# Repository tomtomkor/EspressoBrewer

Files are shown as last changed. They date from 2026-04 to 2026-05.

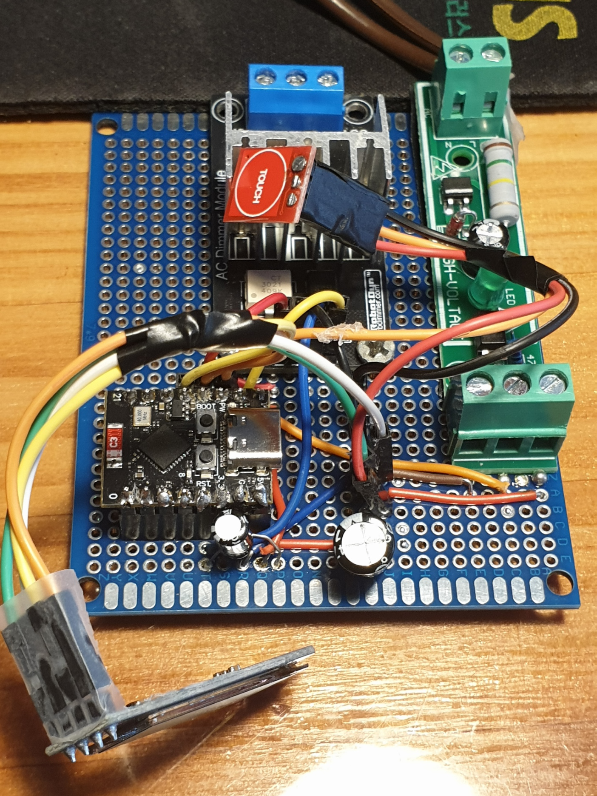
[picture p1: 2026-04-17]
Wiring.jpg

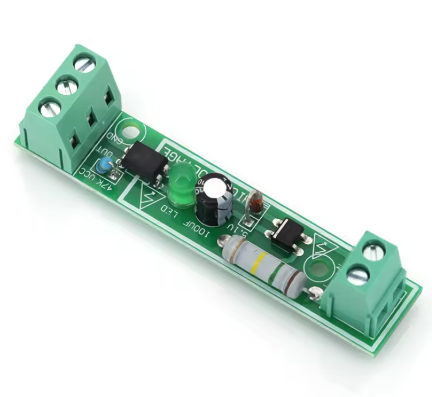
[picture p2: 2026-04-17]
Photos/optocoupler.png

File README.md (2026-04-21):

# ☕ Brew Automation (ESP32-C3)

This project automates the espresso brewing process into three distinct phases: **Pre-infusion**, **Blooming**, and **Extraction**. By adding a dimmer and an ESP32-C3 to a classic machine like the Gaggia Classic, you can achieve custom pressure profiling based on your favorite recipes.

---

## 🛠 Hardware Requirements

* **Controller:** ESP32-C3 SuperMini (chosen for its compact form factor)
* **Dimmer:** Robotdyn AC Dimmer module (4A or higher model; controls pump power)
* **Sensor:** AC Optocoupler isolation module or 110V/220V AC Voltage Detection Module Output Level 3-8V (detects the status of the extraction button)
* **Input:** TTP223 Touch sensor (Mode toggle: Manual / Automatic Brew)
* **Display:** 0.91" OLED (I2C)
* **Power Stability:** 100µF or higher Capacitor for dimmer (recommended for stabilizing power to the Dimmer/Pump logic.  Place the capacitor like a bridge between the 5V and GND pins on ESP32C3. Make sure the minus(-) side goes to GND.)
* **Build:** Perfboard (7x9 cm recommended to withstand pump vibration)
* **Case:** 3D printed enclosure (`EspressoBrewerCase.stl` included)

> **Note:** 5V output of ESP32C3 to Dimmer. 3.3V to other modules.

---

## 📱 Software

* **Arduino Code (`EspressoBrewer.ino`):** Should be compiled and uploaded to ESP32-C3 via Arduino IDE.
* **Mobile App (`BrewMate.apk`):** Built using [MIT App Inventor](https://appinventor.mit.edu).
  * The associated source file (`BrewMate.aia`) is uploaded; you can modify and rebuild it if needed.

---

## 🔄 Workflow

1. **Manual Mode (Default):** On power-up, the machine starts in Manual mode. The pump operates at full capacity, allowing you to purge air or flush the group head.
2. **Mode Toggle:** Tap the touch sensor to switch between **Manual** and **Brew** modes.
3. **Warm-up:** In Brew mode, the system waits for a warmup period (Default: 5 min). 
   * *Note: Based on my Gaggia Classic with PID (XMT 7100), it takes about 5 minutes for the 105°C boiler temp to stabilize. You can adjust the `warmupLimit` variable in the Arduino file.*
4. **Pre-infusion:** Turn the extraction switch ON. The pump runs at a user-specified power level for a set duration(0~20 seconds).
5. **Blooming:** The pump stops completely for a "pause" or blooming phase(0~60s).
6. **Ramping Up:** Pump power gradually increases from 0% to the user-specified max level over 0~15 seconds .
7. **Extraction:** Maintains the specified max pump power until the extraction button is turned OFF manually.
8. **Back-to-Back:** After a shot, the machine reheats and returns to "Ready" status in 2 minutes. (This duration is also adjustable in the CoffeeBrewer.ino file.)
9. **Back Flushing:** Switch to Manual mode via the touch sensor to perform flushing as needed.

---

## ⚙️ Setting Parameters (Mobile App)

You can adjust parameters and manage profiles using the **BrewMate** app:

* **PreTime:** Pre-infusion duration

* **PrePower:** Pump power during pre-infusion

* **Pause:** Blooming duration

* **RampUp:** Duration to reach max power

* **MxPower:** Maximum pump power (e.g., set below 100% for "Turbo Shots")
  
  Multiple brewing profiles can be stored on the mobile app. Users can select a profile by name to sync with the ESP32-C3 for immediate application.

**Connection Details:**

* The app requests the local IP address assigned to the ESP32-C3 (e.g., `192.168.0.110`) on first launch.
* Configure your **SSID**, **Password**, and **Static IP** within the `EspressoBrewer.ino` file.
* The app is designed to be intuitive and can be mastered in minutes without a manual.

---

## 🔌 Wiring

* **Power (L) to Pump** ───→ Optocoupler (L)
* **Dimmer (Output L)** ───→ Pump
* ***Main Power (or PID*) L*** ───→ Dimmer (Input L)
* ***Main Power (or PID*) N*** ───→ Dimmer (N)
* ***Main Power (or PID)*** **N*** ───→ Optocoupler (N)
  *\*If a PID is installed.*

> **Pin Mappings:** Detailed ESP32-C3 pin mappings for each module are documented in the `EspressoBrewer.ino` file.

---

## 📂 Files Included

* `EspressoBrewer.ino`: Main Arduino source code.
* `BrewMate.apk`: Android application for profile management.
* `BrewMate.aia`: MIT App Inventor project file.
* `EspressoBrewerCase.stl`: 3D printable case file.
* `Photos/`: Hardware setup and wiring reference photos.

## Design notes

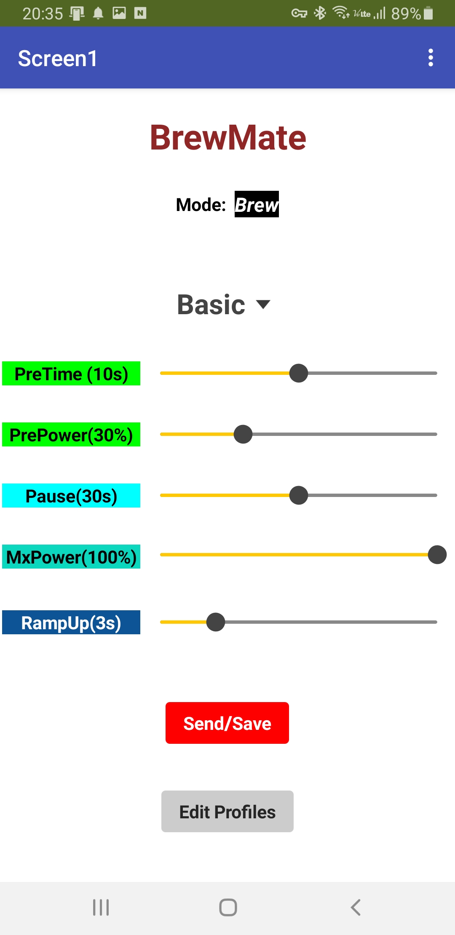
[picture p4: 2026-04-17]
BrewMate.jpg

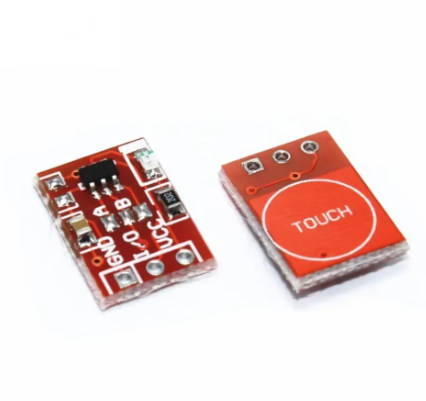
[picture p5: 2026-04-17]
Photos/touch sensor.png

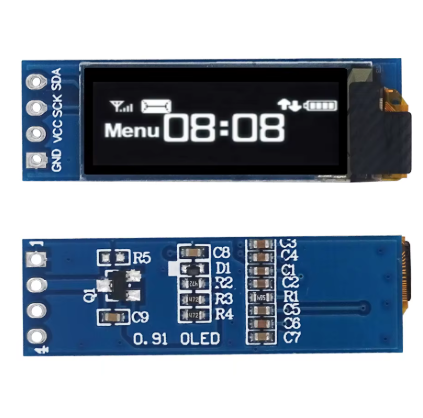
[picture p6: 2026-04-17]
Photos/0.91 OLED.png

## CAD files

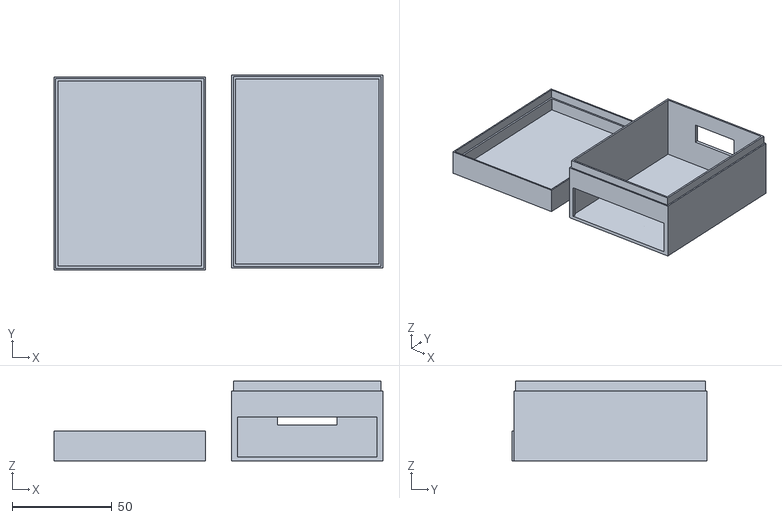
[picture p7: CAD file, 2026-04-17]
EspressoBrewerCase.stl
165.0 x 98.0 x 40.0

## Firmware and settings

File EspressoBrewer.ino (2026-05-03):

#include <Wire.h>
#include <Adafruit_GFX.h>
#include <Adafruit_SSD1306.h>
#include <Preferences.h>
#include <WiFi.h>
#include <WebServer.h>
#include <ArduinoJson.h>
#include "rbdimmerESP32.h"

Preferences prefs;


// ===== RBDimmer =====
#define ZERO_CROSS_PIN   4   // PIN_ZERO_CROSS(ZC)
#define DIMMER_PIN       7   // PIN_DIMMER_OUT (TRIAC)

#define PHASE_NUM        0   

rbdimmer_channel_t* dimmer_channel = NULL;

// ===== Pin setting =====
const int PIN_OPTO_IN    = 5;   // Optocoupler signal pin
const int PIN_TOUCH_IN   = 6;   // Touch sensor signal pin
const int PIN_DIMMER_OUT = 7;   // Dimmer signal pin

#define SCREEN_WIDTH 128
#define SCREEN_HEIGHT 32
Adafruit_SSD1306 display(SCREEN_WIDTH, SCREEN_HEIGHT, &Wire, -1);

bool isReady = false;           
unsigned long powerOnTime = 0;  
int opMode = 1;                 // 0: BREW, 1: MANUAL
String currentProfileName = "Basic"; 
bool isProcessing = false;      
unsigned long brewStartTime = 0; 

int preInfusionPower;                // 0-100%   
int preInfusionTime;    
int pauseTime;
int maxPower;
unsigned long rampUpDuration; 
unsigned long warmupLimit = 300000;  // Time to temp(PID) stabilizization (5min.)

WebServer server(80);
IPAddress local_IP(192, 168, 0, XXX);
IPAddress gateway(192, 168, 0, 1);
IPAddress subnet(255, 255, 255, 0);

const char* ssid = "Your SSID";
const char* password = "password";


void setDimmerLevel(int percent) {
  if (dimmer_channel != NULL) {
    rbdimmer_set_level(dimmer_channel, percent);
  }
}

void displayStatus(String msg, String bigMsg) {
  display.clearDisplay();
  display.setTextColor(SSD1306_WHITE);
  display.setCursor(0, 0); display.setTextSize(1);
  display.println(msg);
  display.setCursor(0, 16); display.setTextSize(2);
  display.println(bigMsg);
  display.display();
}

void updateBrewDisplay(String status, unsigned long startTime) {
  display.clearDisplay();
  display.setTextColor(SSD1306_WHITE);
  display.setCursor(0, 0); display.setTextSize(1);
  display.print(status);
  display.setCursor(0, 16); display.setTextSize(2);
  display.print((millis() - startTime) / 1000);
  display.print(" SEC");
  display.display();
}

void showFinalTime(unsigned long startTime) {
  setDimmerLevel(0); 
  unsigned long total = (millis() - startTime) / 1000;
  displayStatus("TOTAL TIME", String(total) + " SEC");
  delay(5000); 
  isProcessing = false;
}

void checkReadyStatus() {
  if (millis() - powerOnTime > warmupLimit) isReady = true;
  else isReady = false;
}

void runBrewCycle() {
  // Kick-start
  setDimmerLevel(80); 
  delay(150); 

  setDimmerLevel(preInfusionPower);
  brewStartTime = millis(); 
  
  // Phase 1: Pre-Infusion
  while(millis() - brewStartTime < preInfusionTime) {
    if(digitalRead(PIN_OPTO_IN) == HIGH) break;
    static uint32_t lastDisplayUpdate = 0;
    if(millis() - lastDisplayUpdate > 100) { 
        updateBrewDisplay("INFUSING...", brewStartTime);
        lastDisplayUpdate = millis(); 
    }
    yield(); 
  }

  // Phase 2: Pause
  unsigned long pauseStart = millis();
  while(millis() - pauseStart < pauseTime) {
    if(digitalRead(PIN_OPTO_IN) == LOW) break;
    updateBrewDisplay("PAUSING...", brewStartTime);
    setDimmerLevel(0);
    yield();
  }

  // Phase 3: Extraction (Ramp up & Main)
  unsigned long rampStartTime = millis();
  while(digitalRead(PIN_OPTO_IN) == HIGH) {
    unsigned long now = millis();
    int currentPercent = (now - rampStartTime < rampUpDuration) 
                       ? map(now - rampStartTime, 0, rampUpDuration, preInfusionPower, 100) 
                       : 100;
    setDimmerLevel(currentPercent);
    updateBrewDisplay("EXTRACTING: ", brewStartTime);
    yield();
    
    isReady = false;
    powerOnTime = millis();
    warmupLimit = 120000; 
  }
  
  showFinalTime(brewStartTime);
}

void handleExtraction() {
  bool optoState = digitalRead(PIN_OPTO_IN); 

  if (optoState == HIGH) { 
    if (!isProcessing) { 
      brewStartTime = millis(); 
      isProcessing = true; 
      if (opMode == 1) { 
        displayStatus("MANUAL START", ""); 
        for(int i=0; i<=100; i+=15) {
          setDimmerLevel(i);
          delay(10);
        }
      }
    }

    if (opMode == 1) {
      setDimmerLevel(100);
      updateBrewDisplay("PUMPING!", brewStartTime);
    } else {
      runBrewCycle();
    }
  } 
  else if (isProcessing) { 
    showFinalTime(brewStartTime);
  }
}

void handleTouch() {
  static bool lastTouchState = false;
  static unsigned long lastDebounceTime = 0;
  bool currentTouch = digitalRead(PIN_TOUCH_IN);

  if (currentTouch && !lastTouchState && (millis() - lastDebounceTime > 300)) {
    opMode = (opMode == 1) ? 0 : 1;
    lastDebounceTime = millis();
    Serial.printf("Mode changed to: %s\n", opMode == 1 ? "MANUAL" : "BREW");
  }
  lastTouchState = currentTouch;
}

void updateOLED() {
  if (isProcessing) return; 

  display.clearDisplay();
  display.setTextColor(SSD1306_WHITE);
  
  display.setCursor(0, 0); display.setTextSize(1);
  if (opMode == 0) display.print("BREW: " + currentProfileName);
  else display.print("[ MANUAL MODE ]");

  display.setCursor(0, 16); display.setTextSize(2); 
  if (opMode == 0) {
    if (isReady) {display.print("READY!");}
    else {
      long remain = (warmupLimit - (millis() - powerOnTime)) / 1000;
      if (remain < 0) remain = 0;
      display.print("HEAT "); display.print(remain); display.print("s");
    }
  }
  display.display();
}

void savePreferences() {
  prefs.begin("gaggia", false);
  prefs.putInt("prePower", preInfusionPower);
  prefs.putInt("preTime", preInfusionTime);
  prefs.putInt("pauseTime", pauseTime);
  prefs.putULong("rampUp", rampUpDuration);
  prefs.putString("profName", currentProfileName);
  prefs.end();
}

void handleSettings() {
  if (server.hasArg("plain") == false) return;
  StaticJsonDocument<512> doc;
  deserializeJson(doc, server.arg("plain"));
  
  if (doc.containsKey("name")) currentProfileName = doc["name"].as<String>();
  if (doc.containsKey("prePower")) preInfusionPower = doc["prePower"].as<int>();
  if (doc.containsKey("preTime"))  preInfusionTime  = 1000 * doc["preTime"].as<int>();
  if (doc.containsKey("pause"))    pauseTime        = 1000 * doc["pause"].as<int>();
  if (doc.containsKey("ramp"))     rampUpDuration   = 1000 * doc["ramp"].as<int>();
  
  preInfusionPower = constrain(preInfusionPower, 0, 100);
  
  savePreferences();
  server.send(200, "application/json", "{\"result\":\"OK\"}");
}

void handleStatus() {
  StaticJsonDocument<256> doc;
  doc["isReady"] = isReady;
  doc["opMode"] = (int)opMode;
  String output;
  serializeJson(doc, output);
  server.send(200, "application/json", output);
}

void setup() {
  delay(1000);  // capacitor charging

  Serial.begin(115200);
  powerOnTime = millis();
  
  pinMode(PIN_OPTO_IN, INPUT_PULLUP); 
  pinMode(PIN_TOUCH_IN, INPUT_PULLUP);
  pinMode(PIN_DIMMER_OUT, OUTPUT);
  
  rbdimmer_init();
  rbdimmer_register_zero_cross(ZERO_CROSS_PIN, PHASE_NUM, 0);
  
  //RBDIMMER_CURVE_LINEAR: The light output changes directly with the input signal.
  //RBDIMMER_CURVE_LOGARITHMIC: Changes in the dimming signal happen slower at low level
  //                            and faster at the brighter end     
  rbdimmer_config_t dimmer_config = {
    .gpio_pin = DIMMER_PIN,
    .phase = PHASE_NUM,
    .initial_level = 0,
    .curve_type = RBDIMMER_CURVE_LINEAR
    //.curve_type = RBDIMMER_CURVE_LOGARITHMIC
  };
  
  rbdimmer_create_channel(&dimmer_config, &dimmer_channel);
  setDimmerLevel(0);
  
  Serial.println("RBDimmer initialized successfully!");

  if(!display.begin(SSD1306_SWITCHCAPVCC, 0x3C)) for(;;);
  display.clearDisplay();
  display.display();

  prefs.begin("gaggia", false);
  preInfusionPower   = prefs.getInt("prePower", 40);            // defualt: 40%
  preInfusionTime    = prefs.getInt("preTime", 7000);           // defualt: 7 Sec
  pauseTime          = prefs.getInt("pauseTime", 15000);        // defualt: 10 Sec
  maxPower           = prefs.getInt("maxPower", 100);           // defualt: 100%
  rampUpDuration     = prefs.getULong("rampUp", 4000);          // defualt: 4 Sec
  currentProfileName = prefs.getString("profName", "Basic");
  prefs.end();

  WiFi.config(local_IP, gateway, subnet);
  WiFi.begin(ssid, password);
  
  server.on("/set", HTTP_POST, handleSettings);
  server.on("/status", HTTP_GET, handleStatus);
  server.begin();

  opMode = 1; 
  isProcessing = false;
}

void loop() {
  server.handleClient();
  handleTouch();
  checkReadyStatus();

  static unsigned long lastDisplayUpdate = 0;
  if (millis() - lastDisplayUpdate > 500) {
    updateOLED();
    lastDisplayUpdate = millis();
  }
  handleExtraction();
}

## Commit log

2026-04-17 Fix formatting in README.md for power connections
2026-04-17 Fix typo in README regarding pin mappings
2026-04-17 Update case file name in README
2026-04-18 Correct AC Neutral wiring instructions in README
    Updated wiring instructions for AC Neutral connections in the README.
2026-04-21 Update README with ESP32C3 voltage output notes
    Added note about ESP32C3 voltage outputs.
2026-04-21 Clarify power stability capacitor description
    Updated the wording for the power stability capacitor recommendation in the README.
2026-04-21 Update wording for custom pressure profiling
